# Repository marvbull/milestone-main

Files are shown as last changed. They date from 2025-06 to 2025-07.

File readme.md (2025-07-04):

# 🛠️ Assembly Station and Promotional gift

## 📖 Project Overview

This project involves the development of a **custom assembly station** for the **Baden-Wuerttemberg Cooperative State University (DHBW)**.  
It includes both the **design of a promotional giveaway** and the creation of a dedicated **robot-based assembly system** to mount it efficiently.

The system integrates a self-developed robotic arm and combines mechanical, electronic, and software components to form a complete, automated solution.

## 🎬 Demonstration Videos

Below are videos demonstrating the functionality of the assembly station:

- ▶️ [First Attempt – Basic Functionality Test](https://www.youtube.com/watch?v=XfHKRl_iYHc)  
- ✅ [Final Presentation – Fully Working Setup](https://www.youtube.com/watch?v=XNof5O9abk8)

## 📂 Repository Structure

- `src/` – Core source code (C++, Python, Arduino)
- `hardware/` – Circuit schematics (Altium)
- `cad/` – Mechanical models and assemblies (Fusion360, Creo)
- `docs/` – Technical documentation and risk assessment
- `README.md` – Project overview

## ⚙️ Technologies Used

- **C++ / Python / Arduino** – Embedded and control programming  
- **MATLAB** – Simulation and kinematic modeling  
- **Raspberry Pi** – System coordination and I²C communication  
- **Altium Designer** – PCB and electronics design  
- **Siemens NX / Creo** – Mechanical design and CAD modeling  
- **I²C** – Device communication between modules

## 🚀 Project Status

✅ **Completed**  
All planned development milestones have been achieved. The system is fully implemented, tested, and documented.

## 📄 License

This project is licensed under the **MIT License** – see the [LICENSE](./LICENSE) file for details.

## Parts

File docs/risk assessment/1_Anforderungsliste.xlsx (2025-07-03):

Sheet: Montageeinrichtung
Lfd. Nr | Hauptmerkmal | Anforderung / Spezifikation (Zahlen, Daten, Fakten) | Klassifizierung
A1 | Geometrie | Max. 600 x 400 x 400 mm [L x B x H] | LA | BA = Basisanforderung
A2 | Gewicht | Gewicht: Max. 12 kg | LA | LA = Leistungsanforderung
A3 | Kosten | Budget: Max. 750 € | LA | BE = Begeisterungsanforderung
A4 | Ergonomie | Lautstärke < 85 db (Nach Arbeitsschutzverordnung) | BE
A5 | Sicherheit | Erfüllung CE-Richtlinien | BA
A6 | Sicherheit | Die Maschinenrichtlinie muss eingehalten werden | BA
A7 | Sicherheit | Automatische Abschaltung der Anlage beim Öffnen des Gehäuses | BA
A8 | Sicherheit | Not-Aus muss vorhanden sein | BA
A9 | Sicherheit | Eingreifen während des Prozesses ist nicht möglich | LA
A10 | Sicherheit | Kein Zugang zum Montageprozess über das Ausgabefach | BA |  | wenn wir das reinschreiben, müssen wir es am ende auch nachweisen
A11 | Sicherheit | Keine Verletzungsgefahr am Gehäuse | LA
A12 | Sicherheit | Gehäuse: Schutz nach IP41 | LA
A13 | Sicherheit | Sicherer Stand | LA
A14 | Sicherheit | Transportsicher, 90° Kippung | BE
A15 | Elektrik | EMV-Richtlinie | BA
A16 | Elektrik | Elektrische Komponenten schutz | LA
A17 | Zeit | 10 Produkte in <5 min | LA
A18 | Lagerkapazität | Alle Lager müssen mindestens 10 Teile aufnehmen können | LA
A19 | Antrieb | Niederspannung (< 50 V) | LA
A20 | Energie | Elektrische Energie | BE
A21 | Produktivität | Montageablauf: vollautomatisch min. 3 Bauteile fügen | BA
A22 | Betrieb | Automatische Ausgabe des Produktes | BA
A23 | Bedienung | Interaktives Element | BE
A24 | Bedienung | Einzelkomponenten Füllstand (rot, grün) | BE
A25 | Werkstoff | Korrosionsbeständig | BE
A26 | Instandhaltung | Definierter Wartungszyklus /-aufwand | LA
A27 | Lebensdauer | Mind. 10.000 Montagezyklen ohne Reparatur | LA
A28 | Transport | Transportgriffe | BE
A29 | Design | Werbung für DHBW | BE
A30 | Design | Beleuchtung | BE
A31 | Design | Quetschsicheres Design | LA
A32 | Design | Einheitliches Design in DHBW Farben | BE
A33 | Design | Modulares Baugruppendesign | BE
A34 | Design | Sichtbarer, innovativer Montageprozess | LA

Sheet: Werbegeschenk
Lfd. Nr | Hauptmerkmal | Anforderung / Spezifikation (Zahlen, Daten, Fakten) | von wem | wann | Klassifizierung
A1 | Teile | min. 3 Bauteile |  |  | BA
A2 | Werkstoff | Korrosionsbeständig |  |  | BE
A3 | Preis | Preis pro Einzelstück: Max. 10 € |  |  | LA
A4 | Design | Werbung für DHBW |  |  | BE
A5 | Design | Magnet: N48H NdFeB mit 7 µm bis 13 µm NiCuNi Beschichtung |  |  | BA | **Apple Vorgabe
A6 | Sicherheit | Kindersicherheit, keine scharfen Kanten |  |  | LA
A7
 | Kapazität | verstauen von mind. 3 Karten möglich
 | Erweiterbar | erweiterbar um Module/Zwischenschichten, wie Geldfach
 | Sicherheit | auch bei Schütteln fallen Karten nicht raus
 | Stabilität | beide Platten müssen einen Sturz aus 3m höhe und ein Biegemoment von 10 Nm aushalten

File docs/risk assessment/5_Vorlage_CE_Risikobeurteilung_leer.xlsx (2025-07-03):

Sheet: Grenzen der Maschine
Grenzen einer MusterMaschine / eines MusterProduktes
Bestimmungsgemäße Nutzung
Die automatisierte Montageeinrichtung ist ausschließlich für den Zusammenbau des DailyM8's konzipiert. Dabei dürfen die Magazine nur mit den definierten Einzelteilen manuell aufgefüllt werden. Für diese manuelle Handhabung und für wartungsgemäße Arbeiten an der Anlage darf die Schutzklappe geöffnet werden. Bevor der Montageprozess jedoch startet muss die Schutzvorrichtung wieder verschlossen werden. Nach dem Start des Prozesses ist dieser nicht mehr zu unterbrechen, außer es ist ein Not-Halt erforderlich. Das fertige Produkt kann anschließend aus dem Ausgabefach entnommen werden.
Betriebsarten:
Automatisierter Prozess zur Herstellung von 10 DailyM8's
Stoppbetrieb zur manuellen Beladung der Magazine
Nothalt
Einsatzbereich:
Die automatisierte Montageeinrichtung wird ausschließlich in klimatisierten Innenräumen auf stabilem und geradem Untergrund.
Personenkreise, die mit der Maschine / dem Produkt in Berührung kommen
Eingewiesene Personen der DHBW Heidenheim.
Lebensphasen* | Personenkreise
 | MA Fertigung Montage | MA Lager | MA der Logisitk | Händler + MA | Kunde | Wartungs-personal | Kundendienst-MA | Schrott- händler
Produktion | x | x
Montage | x | x
Transport | x | x | x | x
Inbetriebnahme |  |  |  | x | x |  | x
Betrieb |  |  |  |  | x
Instandhaltung / Wartung |  |  |  |  | x | x
Fehlerfall |  |  |  |  | x | x | x
Außerbetriebnahme |  |  |  |  | x |  | x | x
Demontage |  |  |  |  | x |  | x | x
MA = Mitarbeiter
* s. Tabellenblatt Lebensphasen
Räumliche Grenzen (Wandabstand)
Die automatisierte Montageeinrichtung muss mindestens mit einem Abstand von 0,5 m zu jeder Wandseite betrieben werden.
Zeitliche Grenzen
Ein Durchlauf von 10 Produkten erfolgt in unter 5 min Betrieb und muss anschließend manuell aufgefüllt werden.
Weitere Grenzen
Betriebstemperatur: 10 °C bis 30 °C (Optimalfall: Raumtemperatur von 20 °C)
Luftfeuchtigkeit: relative Luftfeuchtigkeit von max. 70 %
Untergrund: Stabil, gerade und sauber
Bedienung: Nur durch unterwiesenes Personal
Vernünftigerweise vorhersehbare Fehlanwendungen:
Definition (vernünftigerweise vorhersehbare Fehlanwendungen): Tätigkeiten die mit der Maschine / dem Produkt innerhalb der gesamten Lebensdauer durch den in der Lebensphase jeweils definierten Personenkreis (z.B. Nutzer, Bedien- oder Fachpersonal) fälschlicherweise, vorsätzlich oder fahrlässig außerhalb der Grenzen der Maschine / des Produktes durchgeführt werden.
Auf richtiges Einlegen der definierten Komponenten an den definierten Orten ist zu achten.
Der Einsatz nicht genehmigter Hilfsstoffe ist nicht gestattet.
Der Einsatz in explosionsgefährdeten Bereichen ist verboten.
Es ist auf die vorgegebenen Wartungsintervalle zu achten.
Jegliche Störungen müssen sofort gemeldet werden und die Maschine ist aus dem Betrieb zu nehmen.
Warn- und Hinweisschilder dürfen nicht entfernt, bedeckt oder geändert werden.
Veränderungen an der Anlage sind nur mit schriftlicher Genehmigung gestattet.
Eingreifen über den Auswerfbehälter ist nicht gestattet.

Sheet: Lebensphasen
Lebensphasen für die Risikobeurteilung zur CE-Konformität
Produktion / Montage
Transport
Inbetriebnahme (Zusammenbau, Installation)
Betrieb
Instandhaltung / Wartung
Fehlerfall
Außerbetriebnahme
Demontage

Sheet: Aufgaben+Tätigkeiten
Aufgaben in der Lebensphase
Lfd. Nr. | Aufgabe / Tätigkeit
1
1 | Mülltrennung
2 | Einzelteile montieren
3 | Funktionstest von Elektrokomponenten
4 | Elektrokomponenten fachgerecht installieren
5 | Elektrokomponenten verlöten
6 | Verpacken
7 | Einladen
8 | Ausladen
9 | Entpacken
10 | Gehäuse verschrauben
11 | Funktionstest der Anlage
12 | Ladungssicherung
13 | Anschließen an Stromnetz
14 | Einweisung
15 | Magazine bestücken
16 | Anschalten
17 | Schutzhaube schließen
18 | Montagezyklus starten
19 | Ersatzteile lagern
20 | Partikuläre Demontage
21 | Not-Halt kontrollieren
22 | Fehler suchen
23 | Endmontage
24 | Wartungsprotokoll ausfüllen
25 | Reinigung der Anlage
26 | Magazine entleeren
27 | Kabel überprüfen
28 | Ursache finden und beseitigen
29 | Abschließen vom Stromnetz
30 | Demontage
31 | Mülltrennung
32 | Schrottabholung
33 | Montage

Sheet: Risikobeurteilung
Risikobeurteilung |  |  | Mustermaschine |  |  |  |  |  |  |  |  |  |  | Erstellt von: Häberle Annika
nach DIN EN ISO 12100:2011 |  |  |  |  |  |  |  |  |  |  |  |  |  | Gruppe 4 | Datum: 28.04.2025
Risikoanalyse |  |  |  |  |  | Risikobewertung
 |  |  |  |  |  |  |  |  |  |  |  |  |  |  |  |  |  |  |  |  | X
Lfd. Nr. | Lebensphase | Aufgabe/ Tätigkeit | Ursprung der Gefährdung durch Maschine, Umwelt und Mensch | Gefährdungsereignis | Folge der Gefährdung für Mensch | Häufigkeit (F) | Wahrscheinlichkeit (W) | Vermeidung (P) | Schwere (S) | Ergebnis (SIL) | konstruktive Maßnahme/ Verbesserung | Schutzmaßnahmen (technisch: ZUSÄTZLICHE Hard- und Software, Mechanik) | Montageanweisung | Handbuch (Betriebsanleitung) | Häufigkeit (F) | Wahrscheinlichkeit (W) | Vermeidung (P) | Schwere (S) | Ergebnis (SIL) | Warnung vor Restrisiken |  | Lebensphase | Anwendung/Funktion | Aufgabe/ Tätigkeit | Ursprung der Gefährdung durch Maschine, Umwelt und Mensch | Gefährdungsereignis | Folge der Gefährdung für Mensch
1 | Produktion / Montage | Transport der Einzelteile | U1.6 herabfallende Gegenstände | Herabfallen oder Ausstoß von Objekten | F1.3 Quetschen | 3 | 3 | 3 | 2 | AM |  |  |  |  |  |  |  |  |  |  |  | Produktion / Montage (beim Hersteller, innerbetrieblich) | Test | #REF! | Ursprung | Ausfall von Einrichtungen zum Anhalten von sich bewegenden Teilen | F1 Mechanische Gefährdung
2 |  |  | U1.14 scharfe Kanten | Kontakt mit scharfen Kanten und Ecken, vorstehenden Teilen | F1.4 Schneiden oder Abschneiden | 3 | 4 | 2 | 2 | AM |  |  |  |  |  |  |  |  |  |  |  | Transport (innerbetrieblich) | #REF! | #REF! | U1 Mechanische Gefährdung | Bruch während des Betriebs | F1.1 überfahren werden
3 |  |  | U1.7 Schwerkraft (gespeicherte Energie) | schmerzhafte und ermüdende Körperhaltungen | F5.5 Wirbelsäulenverletzung | 2 | 3 | 1 | 3 | AM |  |  |  |  |  |  |  |  |  |  |  | Transport (zum Kunden) | #REF! | #REF! | U1.1 Beschleunigung/Abbremsung (kinetische Energie) | direkter Kontakt | F1.2 weggeschleudert werden
4 |  | Einzelteile montieren | U1.6 herabfallende Gegenstände | Herabfallen oder Ausstoß von Objekten | F1.3 Quetschen | 3 | 4 | 3 | 3 | SIL1 |  |  |  |  |  |  |  |  |  |  |  | Transport (beim Kunden innerbetrieblich) | #REF! | #REF! | U1.2 spitze Teile | Durchschlag | F1.3 Quetschen
5 |  |  | U1.7 Schwerkraft (gespeicherte Energie) | schmerzhafte und ermüdende Körperhaltungen | F5.5 Wirbelsäulenverletzung | 2 | 2 | 1 | 3 | AM |  |  |  |  |  |  |  |  |  |  |  | Inbetriebnahme (Zusammenbau, Installation) | #REF! | #REF! | U1.3 Annäherung eines sich bewegenden Teiles | Emission eines Geräuschpegels, der gefährdend sein kann | F1.4 Schneiden oder Abschneiden
6 |  |  | U1.3 Annäherung eines sich bewegenden Teiles | Verschieben sich bewegender Teile | F1.3 Quetschen | 2 | 2 | 3 | 4 | SIL2 |  | Handschuhe tragen | Montage zu 2. |  | 2 | 1 | 2 | 3 | AM |  |  | Einrichten | #REF! | #REF! | U1.4 schneidende Teile | Emission eines Geräuschpegels, der zu Störungen der Sprachkommunikation oder zu Störungen akustischer Signale führen kann | F1.5 Einziehen oder Fangen
7 |  |  | U1.14 scharfe Kanten | direkter Kontakt | F1.4 Schneiden oder Abschneiden | 3 | 4 | 3 | 3 | SIL1 |  |  |  |  |  |  |  |  |  |  |  | Betrieb | #REF! | #REF! | U1.5 elastische Elemente | Emission eines Schwingungspegels, der gefährdend sein kann | F1.6 Erfassen
8 |  |  |  | Kontakt mit scharfen Kanten und Ecken, vorstehenden Teilen | F1.4 Schneiden oder Abschneiden | 3 | 3 | 4 | 3 | SIL1 |  |  |  |  |  |  |  |  |  |  |  | Reinigung | #REF! | #REF! | U1.6 herabfallende Gegenstände | Emission eines Stoffes, der gefährdend sein kann | F1.7 Reiben oder Abschürfen
9 |  | Funktionstest von Elektrokomponenten | U2.4 spannungsführende Teile | direkter Kontakt | F2.8 (elektrischer) Schlag | 2 | 3 | 3 | 3 | SIL1 |  |  |  |  |  |  |  |  |  |  |  | Instandhaltung / Wartung | #REF! | #REF! | U1.7 Schwerkraft (gespeicherte Energie) | Emission von Strahlungsfeldern, die gefährdend sein können | F1.8 Stoß
10 |  |  | U2.6 Überlast | Kurzschluss | F2 Elektrische Gefährdungen | 1 | 1 | 3 | 2 | - |  |  |  |  |  |  |  |  |  |  |  | Fehlerfall | #REF! | #REF! | U1.8 Höhe gegenüber dem Boden | Feuer | F1.9 Eindringen von unter Druck stehenden Medien
11 |  |  | U2.8 Kurzschluss | Kurzschluss | F2.8 (elektrischer) Schlag | 1 | 2 | 3 | 2 | - |  |  |  |  |  |  |  |  |  |  |  | Außerbetriebnahme / Demontage | #REF! | #REF! | U1.9 Hochdruck | Herabfallen oder Ausstoß von Objekten | F1.10 Scheren
12 |  | Elektrokomponenten verlöten | U3.3 Objekte oder Materialien hoher oder niedriger Temperatur | direkter Kontakt | F3.1 Verbrennung | 2 | 3 | 2 | 3 | AM |  |  |  |  |  |  |  |  |  |  |  |  |  | #REF! | U1.10 Beweglichkeit der Maschine | Herabfallen oder Herausschleudern eines sich bewegenden Maschinenteils oder eines in der Maschine festgeklemmten Werkstückes | F1.11 Ausrutschen, Stolpern oder Stürzen
13 |  | Elektrokomponenten fachgerecht installieren | U2.4 spannungsführende Teile | direkter Kontakt | F2.3 Auswirkungen auf medizinische Implantate | 1 | 3 | 4 | 3 | SIL1 |  |  |  |  |  |  |  |  |  |  |  |  |  | #REF! | U1.11 sich bewegende Teile | Herausspritzen von Flüssigkeiten unter hohem Druck | F1.12 Durchstich oder Einstich
14 |  |  | U1.14 scharfe Kanten | direkter Kontakt | F1.4 Schneiden oder Abschneiden | 2 | 3 | 3 | 2 | AM |  |  |  |  |  |  |  |  |  |  |  |  |  | #REF! | U1.12 rotierende Teile | indirekter Kontakt | F1.13 Ersticken
15 |  |  |  | Kontakt mit scharfen Kanten und Ecken, vorstehenden Teilen | F1.4 Schneiden oder Abschneiden | 3 | 3 | 2 | 2 | AM |  |  |  |  |  |  |  |  |  |  |  |  |  | #REF! | U1.13 raue, rutschige Oberfläche | Kontakt mit Objekten hoher oder geringer Temperatur | ./.
16 |  |  | U1.2 spitze Teile | Kontakt mit scharfen Kanten und Ecken, vorstehenden Teilen | F1.12 Durchstich oder Einstich | 3 | 4 | 3 | 1 | - |  |  |  |  |  |  |  |  |  |  |  |  |  | #REF! | U1.14 scharfe Kanten | Kontakt mit rauen Oberflächen | ./.
17 |  |  | U8.3 Gestaltung, Anordnung oder Erkennung | weitere Gefährdungsereignisse durch Ausfälle oder unzureichende Konstruktion der Steuerung | F8.5 alle weiteren (z.B. mechanischen, elektrischen) Probleme als Folge menschlichen Fehlverhaltens | 3 | 4 | 1 | 1 | - |  |  |  |  |  |  |  |  |  |  |  |  |  | #REF! | U1.15 Standfestigkeit/-sicherheit | Kontakt mit rotierenden offenen Enden | ./.
18 |  | Gehäuse verschrauben | U1.6 herabfallende Gegenstände | Herabfallen oder Herausschleudern eines sich bewegenden Maschinenteils oder eines in der Maschine festgeklemmten Werkstückes | F1.3 Quetschen | 2 | 3 | 4 | 3 | SIL1 |  |  |  |  |  |  |  |  |  |  |  |  |  | #REF! | U1.16 Vakuum | Kontakt mit scharfen Kanten und Ecken, vorstehenden Teilen | 0
19 |  | Funktionstest der Anlage | U1.11 sich bewegende Teile | direkter Kontakt | F1.3 Quetschen | 2 | 2 | 1 | 3 | AM |  |  |  |  |  |  |  |  |  |  |  |  |  | #REF! | U1.17 Beschleunigung/Abbremsung | Kurzschluss | 0
20 |  |  | U1.12 rotierende Teile | direkter Kontakt | F1.4 Schneiden oder Abschneiden | 2 | 1 | 3 | 2 | - |  |  |  |  |  |  |  |  |  |  |  |  |  | #REF! | U1.18 Annäherung eines sich bewegenden Teils an ein feststehendes Teil | Lichtbogen | F2 Elektrische Gefährdungen
21 |  |  | U2.4 spannungsführende Teile | direkter Kontakt | F2.3 Auswirkungen auf medizinische Implantate | 3 | 3 | 4 | 3 | SIL1 |  |  |  |  |  |  |  |  |  |  |  |  |  | #REF! | U2 Elektrische Gefährdungen | Maschinentätigkeit als Ergebnis der Wirkungslosigkeit (Umgehen oder Ausfall) von Schutzeinrichtungen | F2.1 Verbrennung
22 |  | Verpacken | U1.14 scharfe Kanten | Kontakt mit scharfen Kanten und Ecken, vorstehenden Teilen | F1.4 Schneiden oder Abschneiden | 2 | 3 | 3 | 1 | - |  |  |  |  |  |  |  |  |  |  |  |  |  | #REF! | U2.1 Lichtbogen | menschliche Fehler/ menschliches Fehlverhalten (unbeabsichtigt und/oder vorsätzlich durch die Konstruktion hervorgerufen) | F2.2 chemische Reaktionen
23 |  |  | U10.1 z.B. sich wiederholende Tätigkeit + Anstrengung + hohe Umgebungstemperatur | übermäßige Anstrengung | F5.5 Wirbelsäulenverletzung | 4 | 2 | 2 | 3 | SIL1 |  |  |  |  |  |  |  |  |  |  |  |  |  | #REF! | U2.2 elektromagnetische Vorgänge | raue Umgebungsbedingungen | F2.3 Auswirkungen auf medizinische Implantate
24 |  | Einladen | U1.7 Schwerkraft (gespeicherte Energie) | schmerzhafte und ermüdende Körperhaltungen | F5.5 Wirbelsäulenverletzung | 4 | 3 | 2 | 3 | SIL1 |  |  |  |  |  |  |  |  |  |  |  |  |  | #REF! | U2.3 elektrostatische Vorgänge | schmerzhafte und ermüdende Körperhaltungen | F2.4 tödlilcher Stromschlag
25 |  |  | U1.6 herabfallende Gegenstände | Herabfallen oder Ausstoß von Objekten | F1.3 Quetschen | 2 | 2 | 2 | 4 | SIL2 |  | Sicherheitsschuhe tragen, Helm tragen |  |  | 1 | 1 | 1 | 4 | SIL2 | Objekte können trotz Sicherung herabfallen |  |  |  | #REF! | U2.4 spannungsführende Teile | sich in hoher Frequenz wiederholende Tätigkeiten | F2.5 Stürzen, weggeschleudert werden
26 |  | Ladungssicherung | U1.6 herabfallende Gegenstände | Herabfallen oder Ausstoß von Objekten | F1.3 Quetschen | 2 | 2 | 1 | 4 | SIL2 |  | Sicherheitsschuhe tragen, Helm tragen |  |  | 1 | 2 | 1 | 3 | - |  |  |  |  | #REF! | U2.5 unzureichender Abstand zu unter Hochspannung stehenden Teilen | übermäßige Anstrengung | F2.6 Feuer
27 |  |  | U1.17 Beschleunigung/Abbremsung | ungesteuerte Bewegungen (einschließlich Geschwindigkeitsänderung) | F1.3 Quetschen | 1 | 2 | 1 | 3 | - |  |  |  |  |  |  |  |  |  |  |  |  |  | #REF! | U2.6 Überlast | unbeabsichtigter/unerwarteter Anlauf | F2.7 Herausschleudern von geschmolzenen Teilen
28 |  | Ausladen | U1.6 herabfallende Gegenstände | Herabfallen oder Ausstoß von Objekten | F1.3 Quetschen | 1 | 2 | 3 | 2 | - |  |  |  |  |  |  |  |  |  |  |  |  |  | #REF! | U2.7 Teile, die im Fehlerzustand spannungsführend geworden sind | ungesteuerte Bewegungen | F2.8 (elektrischer) Schlag
29 |  |  | U1.7 Schwerkraft (gespeicherte Energie) | schmerzhafte und ermüdende Körperhaltungen | F5.5 Wirbelsäulenverletzung | 1 | 2 | 1 | 3 | - |  |  |  |  |  |  |  |  |  |  |  |  |  | #REF! | U2.8 Kurzschluss | ungesteuerte Bewegungen (einschließlich Geschwindigkeitsänderung) | ./.
30 |  |  | U1.8 Höhe gegenüber dem Boden | Herabfallen oder Ausstoß von Objekten | F1.3 Quetschen | 3 | 4 | 4 | 2 | SIL1 |  |  |  |  |  |  |  |  |  |  |  |  |  | #REF! | U2.9 Wärmestrahlung | Verlust der direkten Sichtbarkeit des Arbeitsbereiches | F3 Thermische Gefährdungen
31 |  | Entpacken | U1.2 spitze Teile | direkter Kontakt | F1.3 Quetschen | 2 | 3 | 2 | 2 | - |  |  |  |  |  |  |  |  |  |  |  |  |  | #REF! | U3 Thermische Gefährdungen | Verlust der Standfestigkeit/-sicherheit | F3.1 Verbrennung
32 |  |  |  |  | F1.4 Schneiden oder Abschneiden | 2 | 3 | 3 | 2 | AM |  |  |  |  |  |  |  |  |  |  |  |  |  | #REF! | U3.1 Explosiion | Verschieben sich bewegender Teile | F3.2 Dehydrierung
33 |  |  | U1.14 scharfe Kanten | direkter Kontakt | F1.4 Schneiden oder Abschneiden | 2 | 4 | 2 | 2 | AM |  |  |  |  |  |  |  |  |  |  |  |  |  | #REF! | U3.2 Flamme | weitere Gefährdungsereignisse durch Ausfälle oder unzureichende Konstruktion der Steuerung | F3.3 Unbehagen
34 |  |  |  | Kontakt mit scharfen Kanten und Ecken, vorstehenden Teilen | F1.4 Schneiden oder Abschneiden | 3 | 4 | 3 | 2 | AM |  |  |  |  |  |  |  |  |  |  |  |  |  | #REF! | U3.3 Objekte oder Materialien hoher oder niedriger Temperatur | Zugang zu/Kontakt mit beweglichen Teilen | F3.4 Erfrierung
35 |  |  | U1.13 raue, rutschige Oberfläche | Kontakt mit rauen Oberflächen | F1.7 Reiben oder Abschürfen | 2 | 3 | 3 | 1 | - |  |  |  |  |  |  |  |  |  |  |  |  |  | #REF! | U3.4 Strahlung von Wärmequellen |  | F3.5 Verletzungen durch Strahlung von Wärmequellen
36 |  |  | U1.10 Beweglichkeit der Maschine | Kontakt mit scharfen Kanten und Ecken, vorstehenden Teilen | F1.4 Schneiden oder Abschneiden | 1 | 2 | 3 | 1 | - |  |  |  |  |  |  |  |  |  |  |  |  |  | #REF! | ./. |  | F3.6 Verbrühung
37 |  | Elektrokomponenten fachgerecht installieren | U2.4 spannungsführende Teile | direkter Kontakt | F2.8 (elektrischer) Schlag | 1 | 4 | 3 | 4 | SIL2 | FI-Schutzschalter verwenden |  |  |  | 1 | 2 | 2 | 3 | AM |  |  |  |  | #REF! | ./. |  | F4 Gefährdung durch Lärm
38 |  |  |  |  | F2.3 Auswirkungen auf medizinische Implantate | 1 | 3 | 4 | 3 | SIL1 |  |  |  |  |  |  |  |  |  |  |  |  |  | #REF! | U4 Gefährdung durch Lärm |  | F4.1 Unbehagen
39 |  | Einweisung | U9 Gefährdungen im Zusammenhang mit der Einsatzumgebung der Maschine | menschliche Fehler/ menschliches Fehlverhalten (unbeabsichtigt und/oder vorsätzlich durch die Konstruktion hervorgerufen) | F1.11 Ausrutschen, Stolpern oder Stürzen | 2 | 3 | 5 | 2 | AM |  |  |  |  |  |  |  |  |  |  |  |  |  | #REF! | U4.1 Kavitationsvorgänge |  | F4.2 Bewusstseinsverlust
40 |  | Magazine bestücken | U1.2 spitze Teile | direkter Kontakt | F1.3 Quetschen | 2 | 3 | 3 | 2 | AM |  |  |  |  |  |  |  |  |  |  |  |  |  | #REF! | U4.2 Abluftsystem |  | F4.3 Gleichgewichtsstörung
41 |  |  |  |  | F1.4 Schneiden oder Abschneiden | 2 | 4 | 2 | 2 | AM |  |  |  |  |  |  |  |  |  |  |  |  |  | #REF! | U4.3 mit hoher Geschwindigkeit austretendes Gas |  | F4.4 bleibender Gehörverlust
42 |  |  | U1.14 scharfe Kanten | direkter Kontakt | F1.4 Schneiden oder Abschneiden | 3 | 4 | 3 | 2 | AM |  |  |  |  |  |  |  |  |  |  |  |  |  | #REF! | U4.4 Herstellungsprozess (Stanzen, Schneiden usw.) |  | F4.5 Stress
43 |  |  |  | Kontakt mit scharfen Kanten und Ecken, vorstehenden Teilen | F1.4 Schneiden oder Abschneiden | 2 | 3 | 2 | 2 | - |  |  |  |  |  |  |  |  |  |  |  |  |  | #REF! | U4.5 bewegliche Teile |  | F4.6 Tinnitus (Ohrensausen)
44 |  | Anschalten | U4.8 pfeifende Pneumatik-Einrichtungen | Emission eines Geräuschpegels, der zu Störungen der Sprachkommunikation oder zu Störungen akustischer Signale führen kann | F4.1 Unbehagen | 3 | 3 | 4 | 1 | - |  |  |  |  |  |  |  |  |  |  |  |  |  | #REF! | U4.6 reibende Flächen |  | F4.7 Ermüdung
45 |  |  |  |  | F4.5 Stress | 2 | 3 | 3 | 2 | AM |  |  |  |  |  |  |  |  |  |  |  |  |  | #REF! | U4.7 mit Unwucht rotierende Teile |  | F4.8 alle weiteren (z.B. mechanischen, elektrischen) Probleme als Folge einer Störung der Sprachkommunikation oder einer Störung akustischer Signale
46 |  |  |  |  | F6.5 Kopfschmerzen, Schlaflosigkeit usw. | 4 | 3 | 4 | 1 | AM |  |  |  |  |  |  |  |  |  |  |  |  |  | #REF! | U4.8 pfeifende Pneumatik-Einrichtungen |  | ./.
47 |  |  | U2.4 spannungsführende Teile | direkter Kontakt | F2.3 Auswirkungen auf medizinische Implantate | 1 | 3 | 4 | 3 | SIL1 |  |  |  |  |  |  |  |  |  |  |  |  |  | #REF! | U4.9 verschlissene Teile |  | F5 Gefährdung durch Schwingungen
48 |  |  |  |  | F2.8 (elektrischer) Schlag | 1 | 4 | 3 | 3 | SIL1 |  |  |  |  |  |  |  |  |  |  |  |  |  | #REF! | U5 Gefährdung durch Schwingungen |  | F5.1 Unbehagen
49 |  | Schutzhaube schließen | U1.18 Annäherung eines sich bewegenden Teils an ein feststehendes Teil | direkter Kontakt | F1.3 Quetschen | 1 | 3 | 3 | 3 | AM |  |  |  |  |  |  |  |  |  |  |  |  |  | #REF! | U5.1 Kavitationsvorgänge |  | F5.2 Erkrankungen der unteren Wirbelsäule
50 |  | Montagezyklus starten | U4.8 pfeifende Pneumatik-Einrichtungen | Emission eines Geräuschpegels, der zu Störungen der Sprachkommunikation oder zu Störungen akustischer Signale führen kann | F4.5 Stress | 2 | 3 | 3 | 2 | AM |  |  |  |  |  |  |  |  |  |  |  |  |  | #REF! | U5.2 Fehlausrichtung sich bewegender Teile |  | F5.3 neurologische Erkrankung
51 |  |  |  |  | F4.1 Unbehagen | 3 | 3 | 4 | 1 | - |  |  |  |  |  |  |  |  |  |  |  |  |  | #REF! | U5.3 bewegliche Ausrüstung |  | F5.4 Knochengelenkschaden
52 |  |  |  |  | F6.5 Kopfschmerzen, Schlaflosigkeit usw. | 4 | 3 | 4 | 1 | AM |  |  |  |  |  |  |  |  |  |  |  |  |  | #REF! | U5.4 reibende Flächen |  | F5.5 Wirbelsäulenverletzung
53 |  | Ersatzteile lagern | U1.7 Schwerkraft (gespeicherte Energie) | übermäßige Anstrengung | F5.2 Erkrankungen der unteren Wirbelsäule | 1 | 3 | 2 | 4 | SIL2 |  | Hebehilfen verwenden |  | Wiederholtes Heben kann zu gesundheitlichen Schäden führen | 1 | 2 | 1 | 3 | - |  |  |  |  | #REF! | U5.5 mit Unwucht rotierende Teile |  | F5.6 Gefäßerkrankungen
54 |  |  | U1.6 herabfallende Gegenstände | Herabfallen oder Ausstoß von Objekten | F1.2 weggeschleudert werden | 3 | 3 | 2 | 2 | AM |  |  |  |  |  |  |  |  |  |  |  |  |  | #REF! | U5.6 schwingende Ausrüstung |  | ./.
55 |  | Partikuläre Demontage | U1.6 herabfallende Gegenstände | Herabfallen oder Ausstoß von Objekten | F1.3 Quetschen | 2 | 3 | 2 | 3 | AM |  |  |  |  |  |  |  |  |  |  |  |  |  | #REF! | U5.7 verschlissene Teile |  | F6 Gefährdung durch Strahlung
56 |  |  | U1.7 Schwerkraft (gespeicherte Energie) | schmerzhafte und ermüdende Körperhaltungen | F5.5 Wirbelsäulenverletzung | 2 | 1 | 3 | 4 | SIL2 |  | Hebehilfen verwenden |  | Wiederholtes Heben kann zu gesundheitlichen Schäden führen | 1 | 2 | 1 | 3 | - |  |  |  |  | #REF! | U6 Gefährdung durch Strahlung |  | F6.1 Verbrennung
57 |  |  | U1.14 scharfe Kanten | Kontakt mit scharfen Kanten und Ecken, vorstehenden Teilen | F1.4 Schneiden oder Abschneiden | 3 | 2 | 2 | 2 | - |  |  |  |  |  |  |  |  |  |  |  |  |  | #REF! | U6.1 ionisierende Strahlungsquelle |  | F6.2 Augen- und Hautschädigung
58 |  | Montagezyklus starten | U1.3 Annäherung eines sich bewegenden Teiles | Verschieben sich bewegender Teile | F1.3 Quetschen | 2 | 3 | 2 | 3 | AM |  |  |  |  |  |  |  |  |  |  |  |  |  | #REF! | U6.2 niederfrequente elektromagnetische Strahlung |  | F6.3 Auswirkungen auf die Fortpflanzungsfähigkeit
59 |  |  | U1.7 Schwerkraft (gespeicherte Energie) | schmerzhafte und ermüdende Körperhaltungen | F5.5 Wirbelsäulenverletzung | 2 | 1 | 3 | 3 | AM |  |  |  |  |  |  |  |  |  |  |  |  |  | #REF! | U6.3 optische Strahlung (infrarot, sichtbar und ultraviolett) einschließlich Laserstrahlen |  | F6.4 genetische Veränderung
60 |  |  | U1.6 herabfallende Gegenstände | Herabfallen oder Ausstoß von Objekten | F1.3 Quetschen | 2 | 3 | 2 | 3 | AM |  |  |  |  |  |  |  |  |  |  |  |  |  | #REF! | U6.4 hochfrequente elektromagnetische Strahlung |  | F6.5 Kopfschmerzen, Schlaflosigkeit usw.
61 |  |  | U1.14 scharfe Kanten | direkter Kontakt | F1.4 Schneiden oder Abschneiden | 2 | 3 | 3 | 3 | SIL1 |  |  |  |  |  |  |  |  |  |  |  |  |  | #REF! | ./. |  | F7 Gefährdungen durch Materialien und Stoffe
62 |  |  |  | Kontakt mit scharfen Kanten und Ecken, vorstehenden Teilen | F1.4 Schneiden oder Abschneiden | 1 | 2 | 2 | 3 | AM |  |  |  |  |  |  |  |  |  |  |  |  |  | #REF! | U7 Gefährdungen durch Materialien und Stoffe |  | F7.1 Atembeschwerden, Ersticken
63 |  | Not-Halt kontrollieren | U1.10 Beweglichkeit der Maschine | Ausfall von Einrichtungen zum Anhalten von sich bewegenden Teilen | F9.5 alle weiteren Probleme, die als Folge der Auswirkungen der Gefährdungsquellen an der Maschine oder an Teilen der Maschine auftreten | 1 | 1 | 5 | 3 | AM |  |  |  |  |  |  |  |  |  |  |  |  |  | #REF! | U7.1 Aerosole |  | F7.2 Krebs
64 |  | Wartungsprotokoll ausfüllen | U8.7 psychische Überbelastung/Unterforderung | menschliche Fehler/ menschliches Fehlverhalten (unbeabsichtigt und/oder vorsätzlich durch die Konstruktion hervorgerufen) | F10 Kombination von Gefährdungen | 3 | 3 | 3 | 2 | AM |  |  |  |  |  |  |  |  |  |  |  |  |  | #REF! | U7.2 biologische und mikrobiologische (Viren, Bakterien, Pilze) |  | F7.3 Korrosion
65 |  | Not-Halt betätigen | U1.10 Beweglichkeit der Maschine | Ausfall von Einrichtungen zum Anhalten von sich bewegenden Teilen | F9.5 alle weiteren Probleme, die als Folge der Auswirkungen der Gefährdungsquellen an der Maschine oder an Teilen der Maschine auftreten | 1 | 1 | 5 | 3 | AM |  |  |  |  |  |  |  |  |  |  |  |  |  | #REF! | U7.3 Brennstoffe |  | F7.4 Auswirkungen auf die Fortpflanzungsfähigkeit
66 |  | Fehler suchen | U4.8 pfeifende Pneumatik-Einrichtungen | Emission eines Geräuschpegels, der zu Störungen der Sprachkommunikation oder zu Störungen akustischer Signale führen kann | F4.1 Unbehagen | 3 | 3 | 4 | 1 | - |  |  |  |  |  |  |  |  |  |  |  |  |  | #REF! | U7.4 Stäube |  | F7.5 Explosion
67 |  |  |  |  | F4.5 Stress | 2 | 3 | 3 | 2 | AM |  |  |  |  |  |  |  |  |  |  |  |  |  | #REF! | U7.5 Explosivstoffe |  | F7.6 Feuer
68 |  |  |  |  | F6.5 Kopfschmerzen, Schlaflosigkeit usw. | 4 | 3 | 4 | 1 | AM |  |  |  |  |  |  |  |  |  |  |  |  |  | #REF! | U7.6 Fasern |  | F7.7 Infektion
69 |  |  | U1.2 spitze Teile | direkter Kontakt | F1.3 Quetschen | 2 | 2 | 3 | 2 | - |  |  |  |  |  |  |  |  |  |  |  |  |  | #REF! | U7.7 feuergefährliches Material |  | F7.8 Veränderungen des Erbguts
70 |  |  |  |  | F1.4 Schneiden oder Abschneiden | 3 | 2 | 2 | 3 | AM |  |  |  |  |  |  |  |  |  |  |  |  |  | #REF! | U7.8 Flüssigkeiten |  | F7.9 Vergiftung
71 |  |  | U1.14 scharfe Kanten | direkter Kontakt | F1.4 Schneiden oder Abschneiden | 2 | 2 | 3 | 2 | - |  |  |  |  |  |  |  |  |  |  |  |  |  | #REF! | U7.9 Dämpfe |  | F7.10 Sensibilisierung
72 |  |  |  | Kontakt mit scharfen Kanten und Ecken, vorstehenden Teilen | F1.4 Schneiden oder Abschneiden | 3 | 3 | 2 | 3 | SIL1 |  |  |  |  |  |  |  |  |  |  |  |  |  | #REF! | U7.10 Gase |  | ./.
73 |  |  | U2.7 Teile, die im Fehlerzustand spannungsführend geworden sind | direkter Kontakt | F2.3 Auswirkungen auf medizinische Implantate | 2 | 3 | 4 | 3 | SIL1 |  |  |  |  |  |  |  |  |  |  |  |  |  | #REF! | U7.11 Nebel |  | ./.
74 |  |  |  |  | F2.8 (elektrischer) Schlag | 3 | 4 | 3 | 3 | SIL1 |  |  |  |  |  |  |  |  |  |  |  |  |  | #REF! | U7.12 Oxidationsmittel |  | F8 Gefährdung durch unergonomische Gestaltung
75 |  |  | U2.8 Kurzschluss | Kurzschluss | F2.8 (elektrischer) Schlag | 2 | 3 | 4 | 2 | AM |  |  |  |  |  |  |  |  |  |  |  |  |  | #REF! | U8 Gefährdung durch unergonomische Gestaltung |  | F8.1 Unbehagen
76 |  |  | U5.7 verschlissene Teile | direkter Kontakt | F1.4 Schneiden oder Abschneiden | 2 | 3 | 3 | 3 | SIL1 |  |  |  |  |  |  |  |  |  |  |  |  |  | #REF! | U8.1 Zugang |  | F8.2 Ermüdung
77 |  |  |  |  | F1.7 Reiben oder Abschürfen | 3 | 2 | 2 | 2 | - |  |  |  |  |  |  |  |  |  |  |  |  |  | #REF! | U8.2 Gestaltung oder Anordnung von Anzeigen |  | F8.3 Störungen des Bewegungsapparates
78 |  | Ursache finden und beseitigen | U8.7 psychische Überbelastung/Unterforderung | menschliche Fehler/ menschliches Fehlverhalten (unbeabsichtigt und/oder vorsätzlich durch die Konstruktion hervorgerufen) | F8.4 Stress | 1 | 2 | 1 | 2 | - |  |  |  |  |  |  |  |  |  |  |  |  |  | #REF! | U8.3 Gestaltung, Anordnung oder Erkennung |  | F8.4 Stress
79 |  |  | U2.7 Teile, die im Fehlerzustand spannungsführend geworden sind | direkter Kontakt | F2.8 (elektrischer) Schlag | 2 | 2 | 3 | 2 | - |  |  |  |  |  |  |  |  |  |  |  |  |  | #REF! | U8.4 Anstrengung |  | F8.5 alle weiteren (z.B. mechanischen, elektrischen) Probleme als Folge menschlichen Fehlverhaltens
80 |  |  | U1.11 sich bewegende Teile | unbeabsichtigter/unerwarteter Anlauf | F1.4 Schneiden oder Abschneiden | 3 | 3 | 1 | 4 | SIL2 |  |  |  | Hinweis: Bei Fehlerfall Maschine vom Netz nehmen | 2 | 1 | 1 | 3 | - |  |  |  |  | #REF! | U8.5 Flackern, Blenden, Schattenbildung und stroboskopische Effekte |  | ./.
81 |  | Abschließen vom Stromnetz | U2.7 Teile, die im Fehlerzustand spannungsführend geworden sind | Kurzschluss | F2.8 (elektrischer) Schlag | 2 | 2 | 3 | 2 | - |  |  |  |  |  |  |  |  |  |  |  |  |  | #REF! | U8.6 örtliche Beleuchtung |  | ./.
82 |  |  |  |  | F2.4 tödlilcher Stromschlag | 1 | 2 | 2 | 5 | SIL3 | FI-Schutzschalter verwenden | Schutzhandschuhe anziehen, Feuchtigkeit vermeiden |  |  | 1 | 2 | 1 | 3 | - |  |  |  |  | #REF! | U8.7 psychische Überbelastung/Unterforderung |  | ./.
83 |  | Demontage | U1.6 herabfallende Gegenstände | Herabfallen oder Ausstoß von Objekten | F1.3 Quetschen | 2 | 3 | 2 | 2 | - |  |  |  |  |  |  |  |  |  |  |  |  |  | #REF! | U8.8 Körperhaltung |  | ./.
84 |  |  | U1.14 scharfe Kanten | Kontakt mit scharfen Kanten und Ecken, vorstehenden Teilen | F1.4 Schneiden oder Abschneiden | 3 | 3 | 2 | 3 | SIL1 |  |  |  |  |  |  |  |  |  |  |  |  |  | #REF! | U8.9 sich wiederholende Tätigkeiten |  | ./.
85 |  |  | U1.7 Schwerkraft (gespeicherte Energie) | schmerzhafte und ermüdende Körperhaltungen | F5.5 Wirbelsäulenverletzung | 2 | 2 | 3 | 3 | AM |  |  |  |  |  |  |  |  |  |  |  |  |  | #REF! | U8.10 Sichtbarkeit |  | F9 Gefährdungen im Zusammenhang mit der Einsatzumgebung der Maschine
86 |  | Mülltrennung | U1.2 spitze Teile | Kontakt mit scharfen Kanten und Ecken, vorstehenden Teilen | F1.12 Durchstich oder Einstich | 2 | 3 | 3 | 3 | SIL1 |  |  |  |  |  |  |  |  |  |  |  |  |  | #REF! | U9 Gefährdungen im Zusammenhang mit der Einsatzumgebung der Maschine |  | F9.1 Verbrennungen
87 |  |  | U1.6 herabfallende Gegenstände | Herabfallen oder Ausstoß von Objekten | F1.3 Quetschen | 1 | 2 | 3 | 3 | AM |  |  |  |  |  |  |  |  |  |  |  |  |  | #REF! | U9.1 Staub und Nebel |  | F9.2 leichte Erkrankungen
88 |  |  | U1.14 scharfe Kanten | Kontakt mit scharfen Kanten und Ecken, vorstehenden Teilen | F1.4 Schneiden oder Abschneiden | 3 | 3 | 1 | 4 | SIL2 |  | Schutzhandschuhe tragen bei der Entsorgung |  |  | 2 | 3 | 1 | 3 | AM |  |  |  |  | #REF! | U9.2 elektromagnetische Störungen |  | F9.3 Ausrutschen, Stürzen
89 |  |  |  |  |  |  |  |  |  |  |  |  |  |  |  |  |  |  |  |  |  |  |  | #REF! | U9.3 Blitzschlag |  | F9.4 Ersticken
90 |  |  |  |  |  |  |  |  |  |  |  |  |  |  |  |  |  |  |  |  |  |  |  | #REF! | U9.4 Feuchtigkeit |  | F9.5 alle weiteren Probleme, die als Folge der Auswirkungen der Gefährdungsquellen an der Maschine oder an Teilen der Maschine auftreten
91 |  |  |  |  |  |  |  |  |  |  |  |  |  |  |  |  |  |  |  |  |  |  |  | #REF! | U9.5 Verunreinigungen |  | ./.
92 |  |  |  |  |  |  |  |  |  |  |  |  |  |  |  |  |  |  |  |  |  |  |  | #REF! | U9.6 Schnee |  | ./.
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

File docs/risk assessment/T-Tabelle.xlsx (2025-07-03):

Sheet: T-Tabelle
 | Spezifikationen |  |  |  |  |  |  |  |  |  |  |  |  |  |  |  |  |  |  |  |  |  |  |  |  |  |  |  |  |  |  |  |  |  |  |  |  | Baugruppen
 | Geometrie | Gewicht | Kosten | Ergonomie | Sicherheit | Sicherheit | Sicherheit | Sicherheit | Sicherheit | Sicherheit | Sicherheit | Sicherheit | Sicherheit | Sicherheit | Elektrik | Elektrik | Zeit | Lagerkapazität | Antrieb | Energie | Produktivität | Betrieb | Bedienung | Bedienung | Werkstoff | Instandhaltung | Lebensdauer | Transport | Design | Design | Design | Design | Design | Design | Funktionen |  |  | Lager Flaschenöffnerplatte | Lager Gegenstück | Lagerausschub | Drehteller | Lager Gummiband | Robotterarm | Ausgabe Dayly M8 | Endproduktlager | Gehäuse | Elektronik | Software
 | A1 | A2 | A3 | A4 | A5 | A6 | A7 | A8 | A9 | A10 | A11 | A12 | A13 | A14 | A15 | A16 | A17 | A18 | A19 | A20 | A21 | A22 | A23 | A24 | A25 | A26 | A27 | A28 | A29 | A30 | A31 | A32 | A33 | A34
Gewichtung (aus Paarweisem Vergleich) | 8 | 8 | 9 | 2 | 10 | 10 | 10 | 10 | 10 | 10 | 7 | 5 | 8 | 2 | 10 | 6 | 9 | 8 | 8 | 3 | 10 | 10 | 2 | 2 | 2 | 6 | 6 | 2 | 2 | 2 | 7 | 2 | 2 | 7 | Gew. Summe | nomiert auf max. 10 | Bezeichnung |  |  |  |  |  |  |  |  |  |  |  | SUMME
Einfluss der Funktion auf die Spezifikation [3=sehr stark, 2=stark, 1=wenig; 0=keinen] |  |  |  |  |  |  |  |  |  |  |  |  |  |  |  |  |  |  |  |  |  |  |  |  |  |  |  |  |  |  |  |  |  |  | 0 | #DIV/0! | Lagerung Unterteile (Macsafe) |  |  |  |  |  |  |  |  |  |  |  | 0 | Einfluss der Funktion auf die Arbeitspakete [3=sehr stark, 2=stark, 1=wenig; 0=keinen]
 |  |  |  |  |  |  |  |  |  |  |  |  |  |  |  |  |  |  |  |  |  |  |  |  |  |  |  |  |  |  |  |  |  |  | 0 | #DIV/0! | Lagerung Oberteile (Tool) |  |  |  |  |  |  |  |  |  |  |  | 0
 |  |  |  |  |  |  |  |  |  |  |  |  |  |  |  |  |  |  |  |  |  |  |  |  |  |  |  |  |  |  |  |  |  |  | 0 | #DIV/0! | Ausschub Ober-/Unterteil |  |  |  |  |  |  |  |  |  |  |  | 0
 |  |  |  |  |  |  |  |  |  |  |  |  |  |  |  |  |  |  |  |  |  |  |  |  |  |  |  |  |  |  |  |  |  |  | 0 | #DIV/0! | Klemmen
 |  |  |  |  |  |  |  |  |  |  |  |  |  |  |  |  |  |  |  |  |  |  |  |  |  |  |  |  |  |  |  |  |  |  | 0 | #DIV/0! | Drehteller rotieren |  |  |  |  |  |  |  |  |  |  |  | 0
 |  |  |  |  |  |  |  |  |  |  |  |  |  |  |  |  |  |  |  |  |  |  |  |  |  |  |  |  |  |  |  |  |  |  |  |  | Lagerung Gummibänder
 |  |  |  |  |  |  |  |  |  |  |  |  |  |  |  |  |  |  |  |  |  |  |  |  |  |  |  |  |  |  |  |  |  |  | 0 | #DIV/0! | Gummilager verfahren |  |  |  |  |  |  |  |  |  |  |  | 0
 |  |  |  |  |  |  |  |  |  |  |  |  |  |  |  |  |  |  |  |  |  |  |  |  |  |  |  |  |  |  |  |  |  |  | 0 | #DIV/0! | Gummi auf Platten schieben |  |  |  |  |  |  |  |  |  |  |  | 0
 |  |  |  |  |  |  |  |  |  |  |  |  |  |  |  |  |  |  |  |  |  |  |  |  |  |  |  |  |  |  |  |  |  |  | 0 | #DIV/0! | Ablassen des Dayly M8
 |  |  |  |  |  |  |  |  |  |  |  |  |  |  |  |  |  |  |  |  |  |  |  |  |  |  |  |  |  |  |  |  |  |  | 0 | #DIV/0! | Ausgabe Dayly M8
 |  |  |  |  |  |  |  |  |  |  |  |  |  |  |  |  |  |  |  |  |  |  |  |  |  |  |  |  |  |  |  |  |  |  |  |  | (Lagerung Dayly M8)
 |  |  |  |  |  |  |  |  |  |  |  |  |  |  |  |  |  |  |  |  |  |  |  |  |  |  |  |  |  |  |  |  |  |  | 0 | #DIV/0! | Prozessüberwachung
 |  |  |  |  |  |  |  |  |  |  |  |  |  |  |  |  |  |  |  |  |  |  |  |  |  |  |  |  |  |  |  |  |  |  | 0 | #DIV/0! | Sicherheitsfunktion
 |  |  |  |  |  |  |  |  |  |  |  |  |  |  |  |  |  |  |  |  |  |  |  |  |  |  |  |  |  |  |  |  |  |  | 0 | #DIV/0! | Wartung
 |  |  |  |  |  |  |  |  |  |  |  |  |  |  |  |  |  |  |  |  |  |  |  |  |  |  |  |  |  |  |  |  |  |  |  |  | (Ausstellen)
 |  |  |  |  |  |  |  |  |  |  |  |  |  |  |  |  |  |  |  |  |  |  |  |  |  |  |  |  |  |  |  |  |  |  | 0 | #DIV/0! | Transport
SUMME | 0 | 0 | 0 | 0 | 0 | 0 | 0 | 0 | 0 | 0 | 0 | 0 | 0 | 0 | 0 | 0 | 0 | 0 | 0 | 0 | 0 | 0 | 0 | 0 | 0 | 0 | 0 | 0 | 0 | 0 | 0 | 0 | 0 | 0 |  |  |  | 0 | 0 | 0 | 0 | 0 | 0 | 0 | 0 | 0 | 0 | 0 |  | SUMME

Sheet: Erklärung der Funktionen
Nr. | Funktion | Beschreibung
 | Lagern von Unterteilen (Macsafe) | Bevorratung von Unterteilen in Magazin/Lager (10 Stück)
 | Lagern von Oberteilen (Tool) | Bevorratung von Oberteilen (ebenfalls 10 Stück)
 | Ausschub Unterteil | Lineareinheit bringt Unterteil auf den Drehteller
 | Klemmen | Festklemmen der Teile auf dem Drehteller
 | Drehteller rotieren | Neupositionierung des Drehtellers
 | Ausschub Oberteil | Oberteil wird auf das Unterteil geschoben
 | Gummilager verfahren | Das Lager mit den aufgezogenen Gummis (auf Vierkant) fährt in Position über die zusammengefügten Wallet-Platten.
 | Gummi vereinzeln | Mechanik/Roboterarm greift nur den vordersten Gummi (evtl. mit Führung oder Stopper).
 | Gummi auf Platten schieben | Roboterarm schiebt den Gummi axial vom Vierkant-Lager auf das Wallet – über beide Platten hinweg.
 | Ablassen des Dayly M8 | Fertiges Produkt wird fallen gelassen
 | Ausgabe Dayly M8 | Produkt wird weitertransportiert
 | Prozessüberwachung | Steuerung, Sensorik, Statusanzeigen
 | Sicherheitsfunktion | Not-Halt, Lichtschranke, Schutzverkleidung
 | Wartung ermöglichen | Zugang zu Lagern, Drehteller, Roboter etc.
 | Ausstellen | Ausstellen der Anlage auf Messen
 | Transport | Transport der Anlage

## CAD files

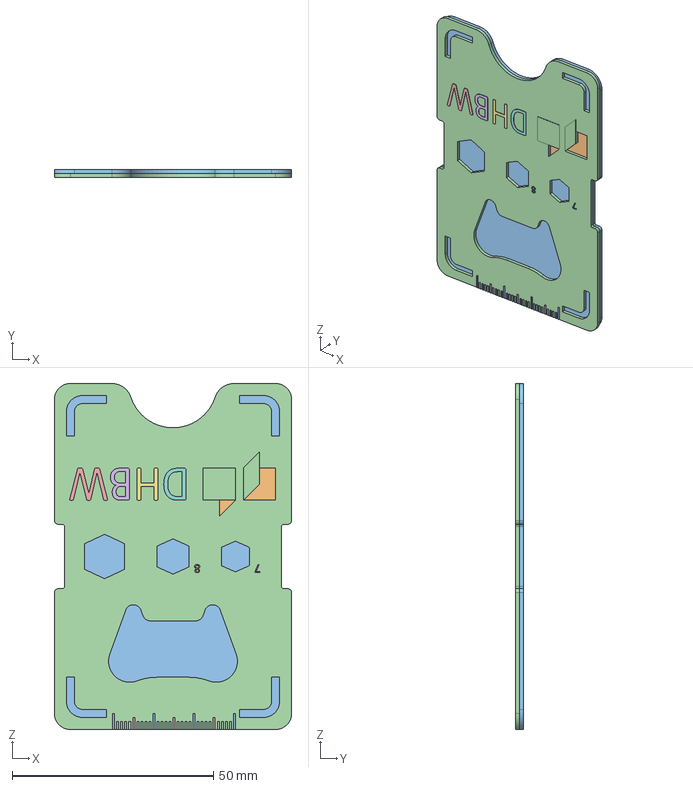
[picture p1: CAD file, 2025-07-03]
cad/giveaway/cad/giveaway_assembly.stp
59.0 x 2.10 x 86.0 mm
ROTE_SEITE
02_UNTERSEITE_MAGSAFE
01_OBERSEITE_TOOL_0040
01_OBERSEITE_TOOL_0041
01_OBERSEITE_TOOL_0042
01_OBERSEITE_TOOL_0043
01_OBERSEITE_TOOL_0044
01_OBERSEITE_TOOL_0045
01_OBERSEITE_TOOL_0046
01_OBERSEITE_TOOL_0047
01_OBERSEITE_TOOL_0048
01_OBERSEITE_TOOL_0049
01_OBERSEITE_TOOL_0050
01_OBERSEITE_TOOL_0051
01_OBERSEITE_TOOL_0052
01_OBERSEITE_TOOL_0053
01_OBERSEITE_TOOL_0054
01_OBERSEITE_TOOL_0055
01_OBERSEITE_TOOL_0056
01_OBERSEITE_TOOL_0057
01_OBERSEITE_TOOL_0058
01_OBERSEITE_TOOL_0059
01_OBERSEITE_TOOL_0060
01_OBERSEITE_TOOL_0061
01_OBERSEITE_TOOL_0062
01_OBERSEITE_TOOL_0063
01_OBERSEITE_TOOL_0064
01_OBERSEITE_TOOL_0065
01_OBERSEITE_TOOL_0066
01_OBERSEITE_TOOL_0067
01_OBERSEITE_TOOL_0068
01_OBERSEITE_TOOL_0069
01_OBERSEITE_TOOL_0070
01_OBERSEITE_TOOL_0071
01_OBERSEITE_TOOL_0072
01_OBERSEITE_TOOL_0073
01_OBERSEITE_TOOL_0074
01_OBERSEITE_TOOL_0075
01_OBERSEITE_TOOL_0076
01_OBERSEITE_TOOL_0077

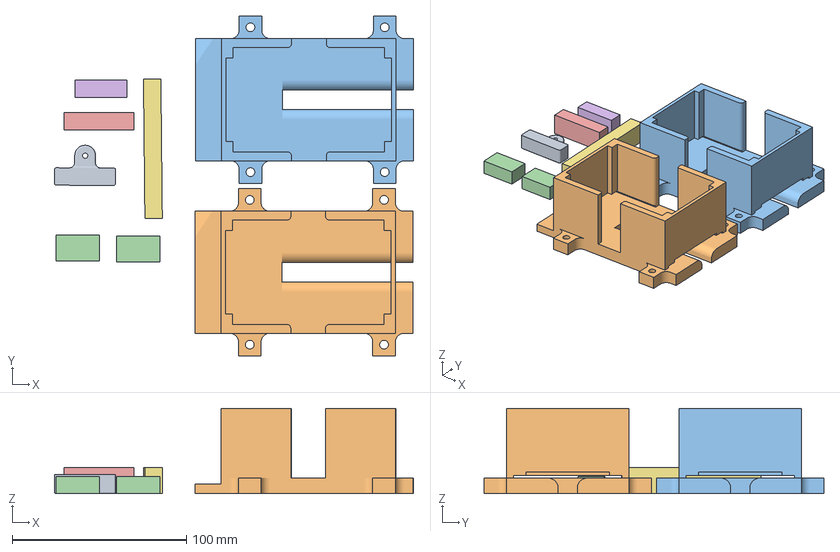
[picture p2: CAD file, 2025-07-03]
cad/3dprint/magazine.3mf
205.9 x 194.9 x 49.0 mm
Stempel_Solenoid.stp
Plattenmagazin_Tool (1).stp x 2
Magnethalterung_Wartungsklappe.stp
Anschlag_Robo_Auswurfbox_groß.stp
Anschlag_Robo_Auswurfbox.stp
Anschlag_Auswurfbox.stp

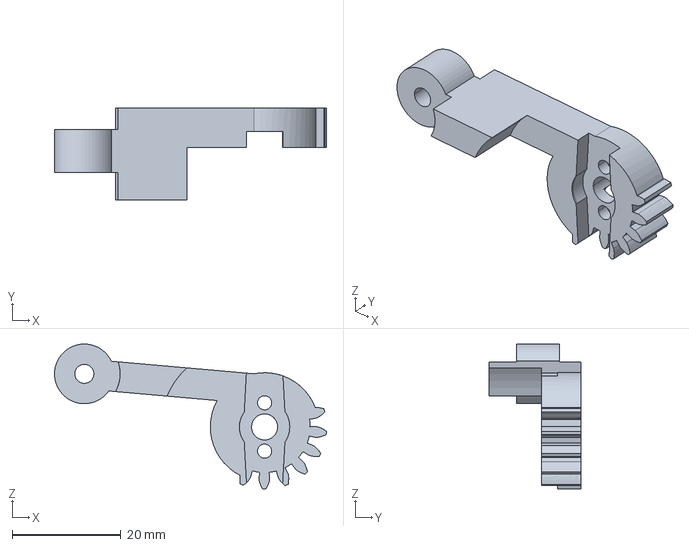
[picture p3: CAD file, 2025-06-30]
cad/robotarm/cad/zahnrad_rechts.stp
50.1 x 16.9 x 26.7 mm

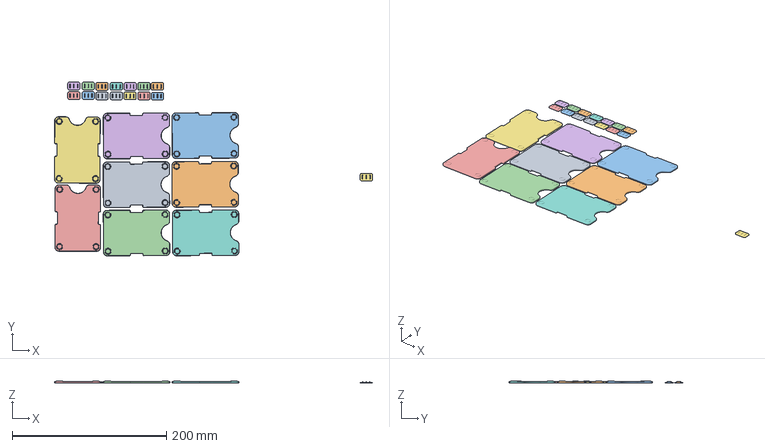
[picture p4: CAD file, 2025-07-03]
cad/3dprint/magsafeplate.3mf
412.6 x 225.6 x 3.20 mm
verschluss_asm.stp x 15
magsafeplatten_logo.stp x 8

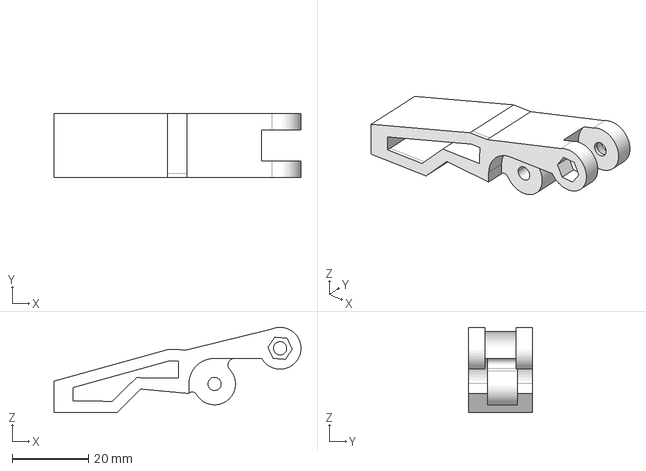
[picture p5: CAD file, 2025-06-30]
cad/robotarm/cad/greiferarm_rechts.stp
65.0 x 16.8 x 22.4 mm

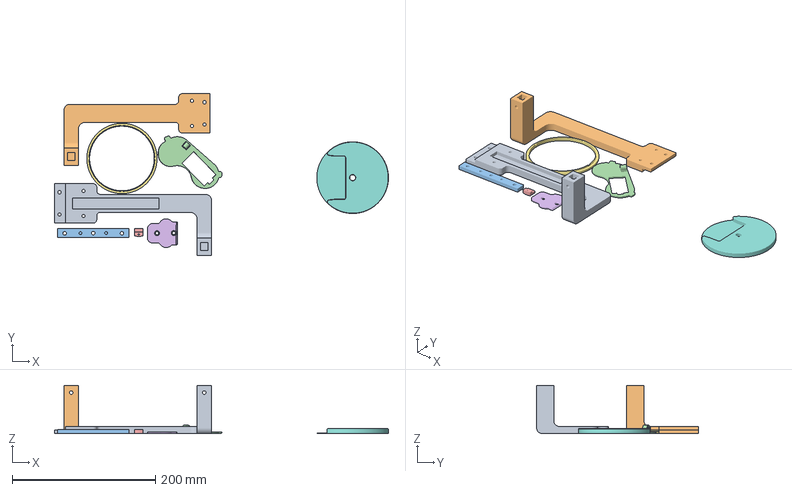
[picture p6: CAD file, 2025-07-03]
cad/3dprint/turntable.3mf
465.9 x 225.6 x 67.2 mm
Schlittenaufsatz_links_V1.stp
Schlittenaufsatz_rechts_V1.stp
neues_magazin_halterung.stp
s2-abdeckung.step
servosicherung.stp
Greiferabeckung.step
schleifring.stp
11_Drehscheibe.stp

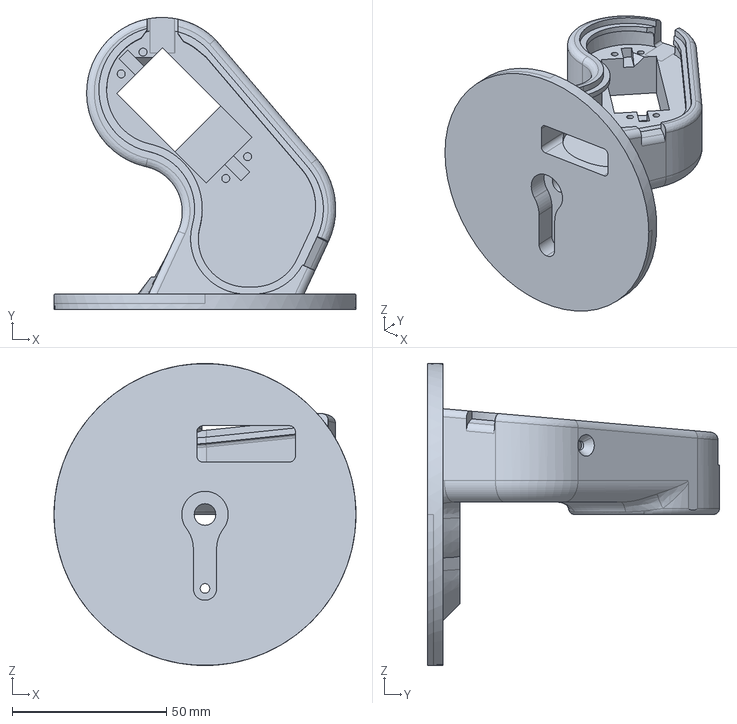
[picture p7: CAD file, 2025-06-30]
cad/robotarm/cad/basegelenk.stp
98.0 x 94.8 x 98.0 mm

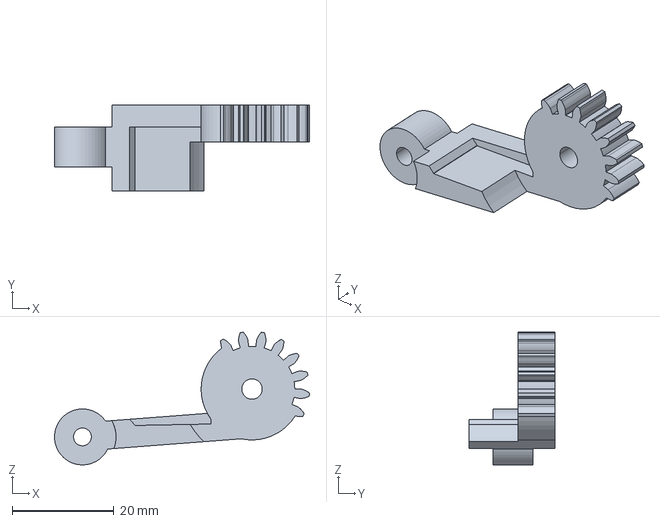
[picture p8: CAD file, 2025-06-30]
cad/robotarm/cad/zahnrad_links.stp
50.1 x 16.9 x 26.1 mm

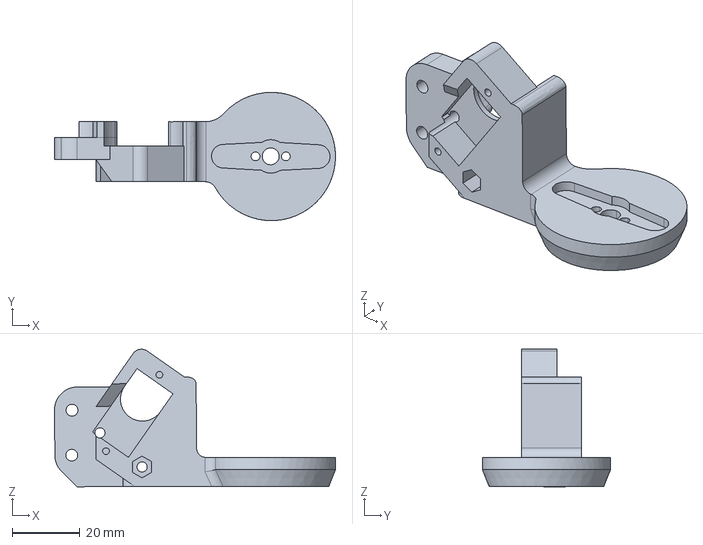
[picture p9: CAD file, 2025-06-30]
cad/robotarm/cad/greifergelenk_1.stp
83.2 x 38.0 x 40.8 mm

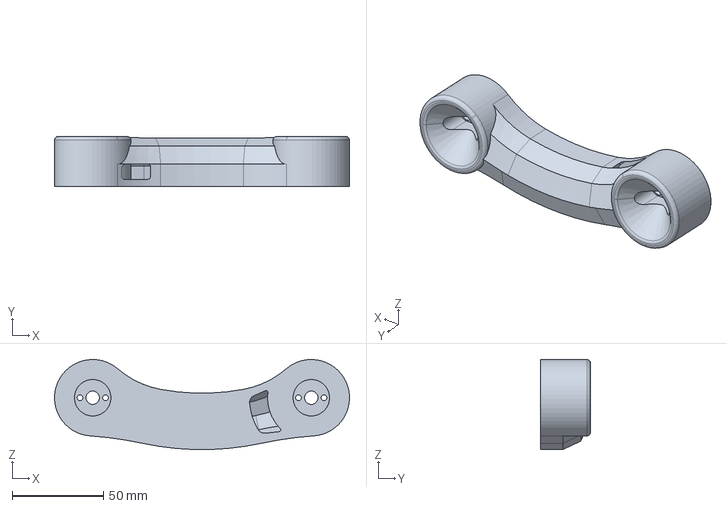
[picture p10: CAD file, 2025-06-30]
cad/robotarm/cad/mittelgelenk.stp
162.0 x 27.5 x 49.4 mm

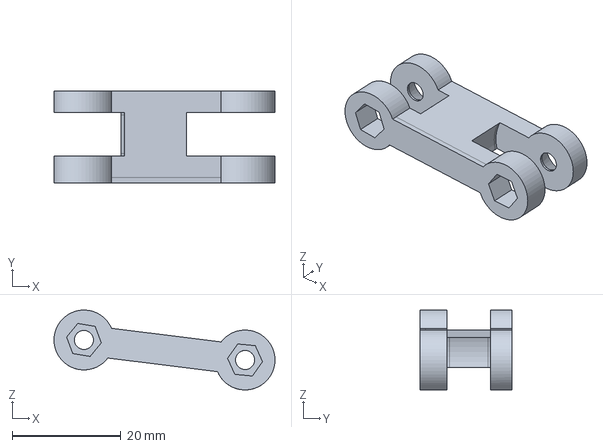
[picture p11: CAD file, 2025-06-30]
cad/robotarm/cad/umlenkung_rechts.stp
40.6 x 16.8 x 14.7 mm

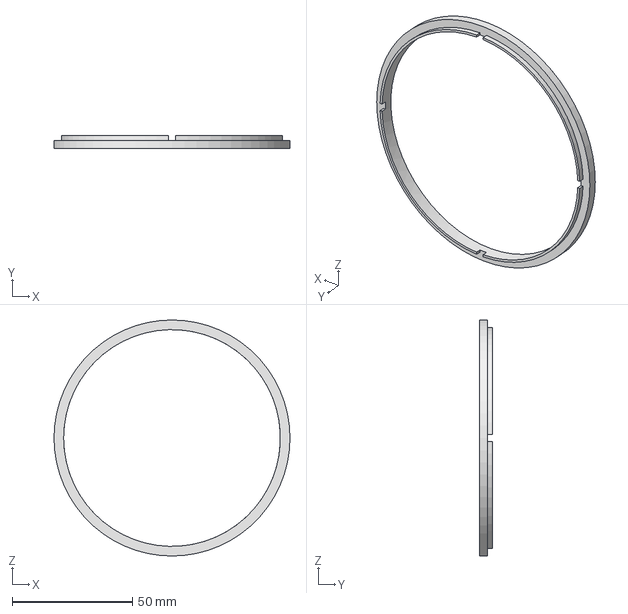
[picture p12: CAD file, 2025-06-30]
cad/robotarm/cad/schleifring.stp
98.0 x 5.20 x 98.0 mm

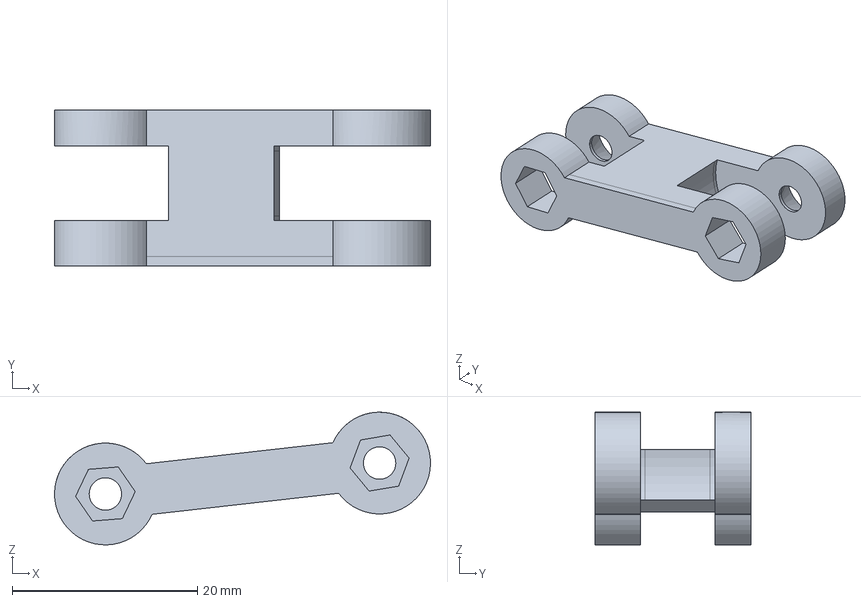
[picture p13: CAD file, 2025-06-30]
cad/robotarm/cad/umlenking_links.stp
40.6 x 16.8 x 14.3 mm

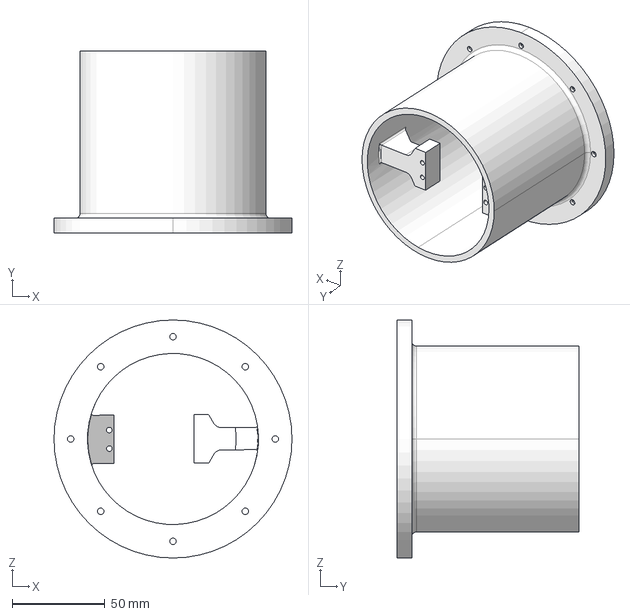
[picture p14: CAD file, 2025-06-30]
cad/robotarm/cad/base.stp
128.0 x 98.0 x 128.0 mm

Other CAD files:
cad/robotarm/cad/greifergelenk_2.stp
cad/robotarm/cad/servosicherung.stp
cad/robotarm/cad/greifergelenk.stp
cad/robotarm/cad/schiebebacke.stp

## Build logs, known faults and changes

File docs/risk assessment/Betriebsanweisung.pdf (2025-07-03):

Nummer: A | BETRIEBSANWEISUNG Betrieb: DailyM8
Bearbeitungsstand: | 06/25 Automatisierte Montageeinrichtung

### Arbeitsplatz/Tätigkeitsbereich: Maschinen- und Anlagenführer

## 1. ANWENDUNGSBEREICH

### Bedienen und Warten einer automatisieren Montageeinrichtung

## 2. GEFAHREN FÜR MENSCH UND UMWELT

- Benutzen der Anlage durch unbefugte Personen
- Quetschgefahr durch bewegende Teile
- Elektrische Gefährdung bei unsachgemäßer Wartung oder defekter Kabel
- Gefährdung durch Unsachgemäße Wartung – Risiko von Bedienfehlern
- Erhöhte Brandgefahr bei Kurzschlüssen oder defekten Netzteilen
- Lärmbelastung durch Antriebe und Mechanik
- Umweltbelastung durch falsche Entsorgung von Materialien

## 3. SCHUTZMAßNAHMEN UND VERHALTENSREGELN

- Die Montageeinrichtung darf nur von ausgebildeten Personen benutzt werden.
- Die Betriebsanleitung des DailyM8-Herstellers sind zu beachten.
- Nur geeignete Einzelbauteile bestimmungsgemäß verwenden.
- Die Montageeinrichtung darf nur mit gültigem Prüfnachweis (Plakette) verwendet werden.
- Regelmäßige Sichtkontrollen auf Beschädigungen und Abnutzung
- Vor dem Einsatz sind alle Schutzeinrichtungen zu prüfen: Stromanschluss, Endschalter und Not-Aus-Schalter
- Innerbetriebliche Sicherheitsregeln beachten.

## 4. VERHALTEN BEI STÖRUNGEN

- Bei sicherheitsrelevanten Störungen (z. B. an Elektrik, Programmierung, usw.) Montageeinrichtung sofort abstellen und Vorgesetzten informieren.
- Mängel nur vom Fachmann beseitigen lassen.

## 5. ERSTE HILFE

- Ersthelfer heranziehen
- Notruf: 112
- Unfall melden
- Durchgeführte Erste – Hilfe – Leistungen immer im Verbandsbuch eintragen

## 6. INSTANDHALTUNG

- Instandhaltung (Wartung, Reparatur) nur von qualifizierten und beauftragten Personen durchführen lassen.
- Bei der Instandhaltung die Betriebs- und Wartungsanleitung des Herstellers beachten.
- Wartung und Reinigung nur im ausgeschalteten und gesicherten Zustand durchführen
- Für die Entsorgung (z.B. Elektronikbauteile) ist zuständig:
Hannes Maurer
- Regelmäßige Prüfungen durch befähigte Personen.

________________________
Unterschrift:
Unternehmer/Geschäftsleitung

Datum: 05.06.2025

Nächster
Überprüfungstermin: 05.06.2026

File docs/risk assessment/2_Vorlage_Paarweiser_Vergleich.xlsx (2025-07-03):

 |  | Paarweiser Vergleich von (Kunden-) Anforderungen
Lfd. Nr. |  | Geometrie | Gewicht | Kosten | Ergonomie | Sicherheit | Sicherheit | Sicherheit | Sicherheit | Sicherheit | Elektrik | Zeit | Lagerkapazität | Antrieb | Energie | Bedienung | Bedienung | Werkstoff | Instandhaltung | Lebensdauer | Transport | Design | Design | Design | Design | Design | Design | Summe | Faktor, ganzzahlig, normiert auf 10 | Prozentwert, normiert
A1 | Geometrie |  | 1 | 1 | 2 | 0 | 1 | 2 | 1 | 2 | 2 | 1 | 1 | 1 | 2 | 2 | 2 | 2 | 2 | 2 | 2 | 2 | 2 | 1 | 2 | 2 | 1 | 39 | 8 | 6.0
A2 | Gewicht | 1 |  | 1 | 2 | 0 | 1 | 2 | 1 | 2 | 2 | 1 | 1 | 1 | 2 | 2 | 2 | 2 | 2 | 2 | 2 | 2 | 2 | 1 | 2 | 2 | 1 | 39 | 8 | 6.0
A3 | Kosten | 1 | 1 |  | 2 | 0 | 2 | 2 | 1 | 2 | 2 | 1 | 1 | 1 | 2 | 2 | 2 | 2 | 2 | 2 | 2 | 2 | 2 | 2 | 2 | 2 | 2 | 42 | 9 | 6.5
A4 | Ergonomie | 0 | 0 | 0 |  | 0 | 0 | 0 | 0 | 1 | 0 | 0 | 0 | 0 | 0 | 1 | 1 | 1 | 0 | 0 | 0 | 1 | 1 | 0 | 1 | 1 | 0 | 8 | 2 | 1.2
A9 | Sicherheit | 2 | 2 | 2 | 2 |  | 2 | 2 | 2 | 2 | 2 | 1 | 1 | 2 | 2 | 2 | 2 | 2 | 2 | 2 | 2 | 2 | 2 | 2 | 2 | 2 | 2 | 48 | 10 | 7.4
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

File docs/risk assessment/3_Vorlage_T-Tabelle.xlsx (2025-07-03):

 | Spezifikationen |  |  |  |  |  |  |  |  |  |  |  |  |  |  |  |  |  |  |  |  |  |  |  | Arbeitspakete
 | Antrieb | Geräuschpegel | Sicherheit | Leistung | Steuerung | Design | Ergonomie | Material | Geschwindigkeit | Flughöhe | Masse | Notfallsysmte | Sensorik | Navigation | EASA | Wartung | Klima- und Heizsystem | Batterieladung | Flugdynamik | Rotoranzahl | Bedienung | Funktionen |  |  | WP1 | WP2 | WP3 | ...
Gewichtung (aus Paarweisem Vergleich) | 10 | 10 | 10 | 10 | 10 | 0 | 3 | 3 | 7 | 10 | 6 | 10 | 9 | 8 | 10 | 6 | 1 | 7 |  |  |  | Gew. Summe | nomiert auf max. 10 | Bezeichnung |  |  |  |  |  |  |  |  |  |  |  | SUMME
Einfluss der Funktion auf die Spezifikation [3=sehr stark, 2=stark, 1=wenig; 0=keinen] | 2 | 3 | 2 | 2 | 3 | 0 | 0 | 0 | 3 | 2 | 2 | 1 | 1 | 1 | 3 | 2 | 1 | 2 | 3 | 3 | 0 | 257 | 10 | Flugfunktion |  |  |  |  |  |  |  |  |  |  |  |  | Einfluss der Funktion auf die Arbeitspakete [3=sehr stark, 2=stark, 1=wenig; 0=keinen]
 | 2 | 3 | 2 | 2 | 3 | 0 | 0 | 0 | 3 | 2 | 2 | 1 | 1 | 1 | 3 | 2 | 1 | 2 | 3 | 3 | 0 | 257 | 10 | Start- und Landungsfunktion
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

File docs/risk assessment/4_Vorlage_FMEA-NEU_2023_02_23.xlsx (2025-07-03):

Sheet: Intro
Die 6 1/2 Schritte einer Design-FMEA

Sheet: 1 Scope
Step 1: Scope
by definition/selection of scope of analysis, ensure consistent alignmnent and orientation!
Describe the project and create the project plan
Set analysis limits
integration of lessons learned from past
definition of team and team responsibility
collect whatever relevant data from available supporting sources
MR: diese Seite füllt d. Moderator

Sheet: 2 Structural analysis
Step 2: Structural Analysis
Determine the structure of the product (derivation from part list if necessary), e.g. Product> Assembly> Sub-Assembly> Components
Remark: Complex structures can be broken down into several structures (work packages) or different levels (block diagrams) and analyzed separately for organizational reasons or for deeper insights
Visualisation of the scope of analysis, e.g. Structure tree, block/demarcation diagrams, 3D models, scatches, etc.
Analysis of relationships, interfaces and interactions between defined system elements
Pre-selection of requirements/ functions/ components, use e.g. KANO, Pairwise comparison, QFD,..
Anm.: diese Seite füllt d. Konstrukteur aus
1st level | 2nd level | 3rd level | 4th level
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

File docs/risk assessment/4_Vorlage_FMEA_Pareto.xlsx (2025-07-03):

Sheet: Intro
Die 6 1/2 Schritte einer Design-FMEA

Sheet: 1 Scope
Step 1: Scope
by definition/selection of scope of analysis, ensure consistent alignmnent and orientation!
Describe the project and create the project plan
Set analysis limits
integration of lessons learned from past
definition of team and team responsibility
collect whatever relevant data from available supporting sources
MR: diese Seite füllt d. Moderator

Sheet: 2 Structural analysis
Step 2: Structural Analysis
Determine the structure of the product (derivation from part list if necessary), e.g. Product> Assembly> Sub-Assembly> Components
Remark: Complex structures can be broken down into several structures (work packages) or different levels (block diagrams) and analyzed separately for organizational reasons or for deeper insights
Visualisation of the scope of analysis, e.g. Structure tree, block/demarcation diagrams, 3D models, scatches, etc.
Analysis of relationships, interfaces and interactions between defined system elements
Pre-selection of requirements/ functions/ components, use e.g. KANO, Pairwise comparison, QFD,..
Anm.: diese Seite füllt d. Konstrukteur aus
1st level | 2nd level | 3rd level | 4th level
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

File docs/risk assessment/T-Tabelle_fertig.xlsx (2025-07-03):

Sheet: T-Tabelle
 | Spezifikationen |  |  |  |  |  |  |  |  |  |  |  |  |  |  |  |  |  |  |  |  |  |  |  |  |  |  |  |  |  |  |  |  |  |  |  |  | Baugruppen
 | Geometrie | Gewicht | Kosten | Ergonomie | Sicherheit | Sicherheit | Sicherheit | Sicherheit | Sicherheit | Sicherheit | Sicherheit | Sicherheit | Sicherheit | Sicherheit | Elektrik | Elektrik | Zeit | Lagerkapazität | Antrieb | Energie | Produktivität | Betrieb | Bedienung | Bedienung | Werkstoff | Instandhaltung | Lebensdauer | Transport | Design | Design | Design | Design | Design | Design | Funktionen |  |  | Lager Flaschenöffnerplatte | Lager Gegenstück | Lagerausschub | Drehteller | Lager Gummiband | Robotterarm | Ausgabe Dayly M8 | Gehäuse | Elektronik | Software | SUMME
 | A1 | A2 | A3 | A4 | A5 | A6 | A7 | A8 | A9 | A10 | A11 | A12 | A13 | A14 | A15 | A16 | A17 | A18 | A19 | A20 | A21 | A22 | A23 | A24 | A25 | A26 | A27 | A28 | A29 | A30 | A31 | A32 | A33 | A34
Gewichtung (aus Paarweisem Vergleich) | 8 | 8 | 9 | 2 | 10 | 10 | 10 | 10 | 10 | 10 | 7 | 5 | 8 | 2 | 10 | 6 | 9 | 8 | 8 | 3 | 10 | 10 | 2 | 2 | 2 | 6 | 6 | 2 | 2 | 2 | 7 | 2 | 2 | 7 | Gew. Summe | nomiert auf max. 10 | Bezeichnung
Einfluss der Funktion auf die Spezifikation [3=sehr stark, 2=stark, 1=wenig; 0=keinen] | 3 | 2 | 1 | 0 | 0 | 0 | 0 | 0 | 0 | 0 | 0 | 0 | 0 | 2 | 0 | 0 | 0 | 3 | 0 | 0 | 1 | 0 | 0 | 3 | 1 | 0 | 0 | 0 | 0 | 0 | 0 | 1 | 2 | 0 | 101 | 2 | Lagerung Unterteile (Macsafe) | 2 | 3 | 3 | 0 | 0 | 0 | 0 | 0 | 0 | 0 | 8 | Einfluss der Funktion auf die Arbeitspakete [3=sehr stark, 2=stark, 1=wenig; 0=keinen]
 | 3 | 2 | 1 | 0 | 0 | 0 | 0 | 0 | 0 | 0 | 0 | 0 | 0 | 2 | 0 | 0 | 0 | 3 | 0 | 0 | 1 | 0 | 0 | 3 | 1 | 0 | 0 | 0 | 0 | 0 | 0 | 1 | 2 | 0 | 101 | 2.337962963 | Lagerung Oberteile (Tool) | 3 | 2 | 3 | 0 | 0 | 0 | 0 | 0 | 0 | 0 | 8
 | 3 | 3 | 2 | 2 | 2 | 2 | 2 | 2 | 1 | 0 | 0 | 0 | 0 | 0 | 2 | 2 | 3 | 0 | 3 | 3 | 3 | 0 | 0 | 0 | 0 | 2 | 1 | 0 | 0 | 0 | 1 | 0 | 3 | 3 | 334 | 7.731481481 | Ausschub Ober-/Unterteil | 3 | 3 | 3 | 1 | 0 | 0 | 0 | 0 | 3 | 3 | 16
 | 1 | 2 | 2 | 1 | 1 | 2 | 2 | 2 | 1 | 0 | 0 | 0 | 0 | 0 | 2 | 1 | 1 | 0 | 2 | 3 | 3 | 1 | 0 | 0 | 0 | 2 | 1 | 0 | 0 | 0 | 3 | 0 | 2 | 2 | 281 | 6.50462963 | Klemmen | 0 | 0 | 0 | 2 | 0 | 0 | 2 | 0 | 3 | 3 | 10
 | 1 | 0 | 1 | 2 | 1 | 1 | 2 | 2 | 1 | 0 | 0 | 0 | 2 | 0 | 2 | 2 | 3 | 0 | 3 | 3 | 3 | 1 | 0 | 0 | 0 | 2 | 1 | 0 | 0 | 0 | 2 | 0 | 2 | 2 | 289 | 6.689814815 | Drehteller rotieren | 0 | 0 | 0 | 3 | 0 | 1 | 2 | 0 | 3 | 3 | 12
 | 3 | 2 | 1 | 0 | 0 | 0 | 0 | 0 | 0 | 0 | 0 | 0 | 0 | 2 | 0 | 0 | 0 | 3 | 0 | 0 | 1 | 0 | 0 | 3 | 1 | 0 | 0 | 0 | 0 | 0 | 0 | 1 | 1 | 0 | 99 | 2.291666667 | Lagerung Gummibänder | 0 | 0 | 0 | 0 | 3 | 0 | 0 | 0 | 0 | 0 | 3
 | 2 | 0 | 2 | 2 | 1 | 2 | 2 | 2 | 1 | 0 | 0 | 0 | 0 | 0 | 2 | 1 | 3 | 0 | 3 | 3 | 3 | 0 | 0 | 0 | 0 | 2 | 1 | 0 | 0 | 0 | 1 | 0 | 1 | 2 | 275 | 6.365740741 | Gummilager verfahren | 0 | 0 | 0 | 1 | 2 | 2 | 0 | 0 | 3 | 3 | 11
 | 3 | 2 | 3 | 2 | 2 | 2 | 2 | 2 | 1 | 0 | 0 | 0 | 1 | 0 | 2 | 2 | 3 | 1 | 3 | 3 | 3 | 0 | 0 | 0 | 0 | 2 | 1 | 0 | 1 | 0 | 1 | 0 | 2 | 3 | 351 | 8.125 | Gummi auf Platten schieben | 0 | 0 | 0 | 0 | 2 | 3 | 0 | 0 | 3 | 3 | 11
 | 2 | 1 | 0 | 2 | 0 | 0 | 0 | 1 | 0 | 0 | 0 | 0 | 1 | 0 | 0 | 0 | 2 | 0 | 1 | 1 | 2 | 1 | 0 | 0 | 0 | 0 | 0 | 0 | 0 | 0 | 0 | 0 | 0 | 0 | 105 | 2.430555556 | Ablassen des Daily M8 | 0 | 0 | 0 | 0 | 0 | 1 | 1 | 0 | 1 | 0 | 3
 | 1 | 0 | 1 | 1 | 3 | 3 | 2 | 2 | 2 | 3 | 2 | 0 | 0 | 0 | 0 | 0 | 1 | 0 | 1 | 2 | 2 | 3 | 0 | 0 | 0 | 0 | 0 | 0 | 1 | 2 | 3 | 1 | 0 | 2 | 299 | 6.921296296 | Ausgabe Daily M8 | 0 | 0 | 0 | 0 | 0 | 0 | 3 | 2 | 1 | 0 | 6
 | 1 | 1 | 3 | 0 | 1 | 1 | 3 | 3 | 3 | 0 | 0 | 0 | 0 | 0 | 3 | 2 | 0 | 2 | 1 | 2 | 1 | 1 | 3 | 3 | 0 | 1 | 0 | 0 | 0 | 1 | 0 | 0 | 0 | 2 | 279 | 6.458333333 | Prozessüberwachung | 0 | 0 | 0 | 1 | 0 | 2 | 1 | 0 | 3 | 3 | 10
 | 1 | 1 | 2 | 0 | 3 | 3 | 3 | 3 | 3 | 3 | 3 | 3 | 3 | 3 | 3 | 3 | 1 | 0 | 2 | 2 | 1 | 1 | 0 | 1 | 2 | 1 | 2 | 3 | 0 | 0 | 3 | 0 | 1 | 0 | 432 | 10 | Sicherheitsfunktion | 0 | 0 | 1 | 1 | 0 | 2 | 2 | 3 | 0 | 0 | 9
 | 1 | 0 | 0 | 0 | 3 | 3 | 3 | 1 | 1 | 1 | 3 | 1 | 1 | 0 | 0 | 2 | 0 | 0 | 1 | 2 | 2 | 0 | 1 | 0 | 1 | 3 | 3 | 0 | 0 | 1 | 1 | 0 | 3 | 0 | 263 | 6.087962963 | Wartung | 1 | 1 | 2 | 1 | 1 | 3 | 0 | 1 | 0 | 0 | 10
 | 2 | 0 | 0 | 3 | 0 | 0 | 2 | 2 | 1 | 1 | 3 | 1 | 1 | 0 | 0 | 0 | 2 | 0 | 0 | 2 | 3 | 3 | 3 | 3 | 1 | 0 | 0 | 1 | 3 | 3 | 0 | 3 | 0 | 3 | 255 | 5.902777778 | Ausstellungsattraktivität | 1 | 1 | 2 | 2 | 1 | 3 | 1 | 2 | 2 | 2 | 17
 | 3 | 3 | 0 | 0 | 0 | 0 | 0 | 0 | 0 | 0 | 3 | 2 | 3 | 3 | 0 | 2 | 0 | 0 | 0 | 0 | 0 | 0 | 0 | 0 | 2 | 0 | 0 | 3 | 0 | 0 | 2 | 0 | 2 | 0 | 149 | 3.449074074 | Transport | 0 | 0 | 0 | 0 | 0 | 1 | 0 | 3 | 0 | 0 | 4
SUMME | 30 | 19 | 19 | 15 | 17 | 19 | 23 | 22 | 15 | 8 | 14 | 7 | 12 | 12 | 16 | 17 | 19 | 12 | 20 | 26 | 29 | 11 | 7 | 16 | 9 | 15 | 10 | 7 | 5 | 7 | 15 | 7 | 19 | 19 |  |  |  | 10 | 10 | 14 | 12 | 9 | 18 | 12 | 11 | 22 | 20 |  | SUMME

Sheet: Erklärung der Funktionen
Nr. | Funktion | Beschreibung
 | Lagern von Unterteilen (Macsafe) | Bevorratung von Unterteilen in Magazin/Lager (10 Stück)
 | Lagern von Oberteilen (Tool) | Bevorratung von Oberteilen (ebenfalls 10 Stück)
 | Ausschub Unterteil | Lineareinheit bringt Unterteil auf den Drehteller
 | Klemmen | Festklemmen der Teile auf dem Drehteller
 | Drehteller rotieren | Neupositionierung des Drehtellers
 | Ausschub Oberteil | Oberteil wird auf das Unterteil geschoben
 | Gummilager verfahren | Das Lager mit den aufgezogenen Gummis (auf Vierkant) fährt in Position über die zusammengefügten Wallet-Platten.
 | Gummi vereinzeln | Mechanik/Roboterarm greift nur den vordersten Gummi (evtl. mit Führung oder Stopper).
 | Gummi auf Platten schieben | Roboterarm schiebt den Gummi axial vom Vierkant-Lager auf das Wallet – über beide Platten hinweg.
 | Ablassen des Dayly M8 | Fertiges Produkt wird fallen gelassen
 | Ausgabe Dayly M8 | Produkt wird weitertransportiert
 | Prozessüberwachung | Steuerung, Sensorik, Statusanzeigen
 | Sicherheitsfunktion | Not-Halt, Lichtschranke, Schutzverkleidung
 | Wartung ermöglichen | Zugang zu Lagern, Drehteller, Roboter etc.
 | Ausstellungsattraktivität | Ausstellen der Anlage auf Messen
 | Transport | Transport der Anlage

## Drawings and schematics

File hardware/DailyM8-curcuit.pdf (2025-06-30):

1 | 2 | 3 | 4 | 5 | 6 | 7 | 8

A

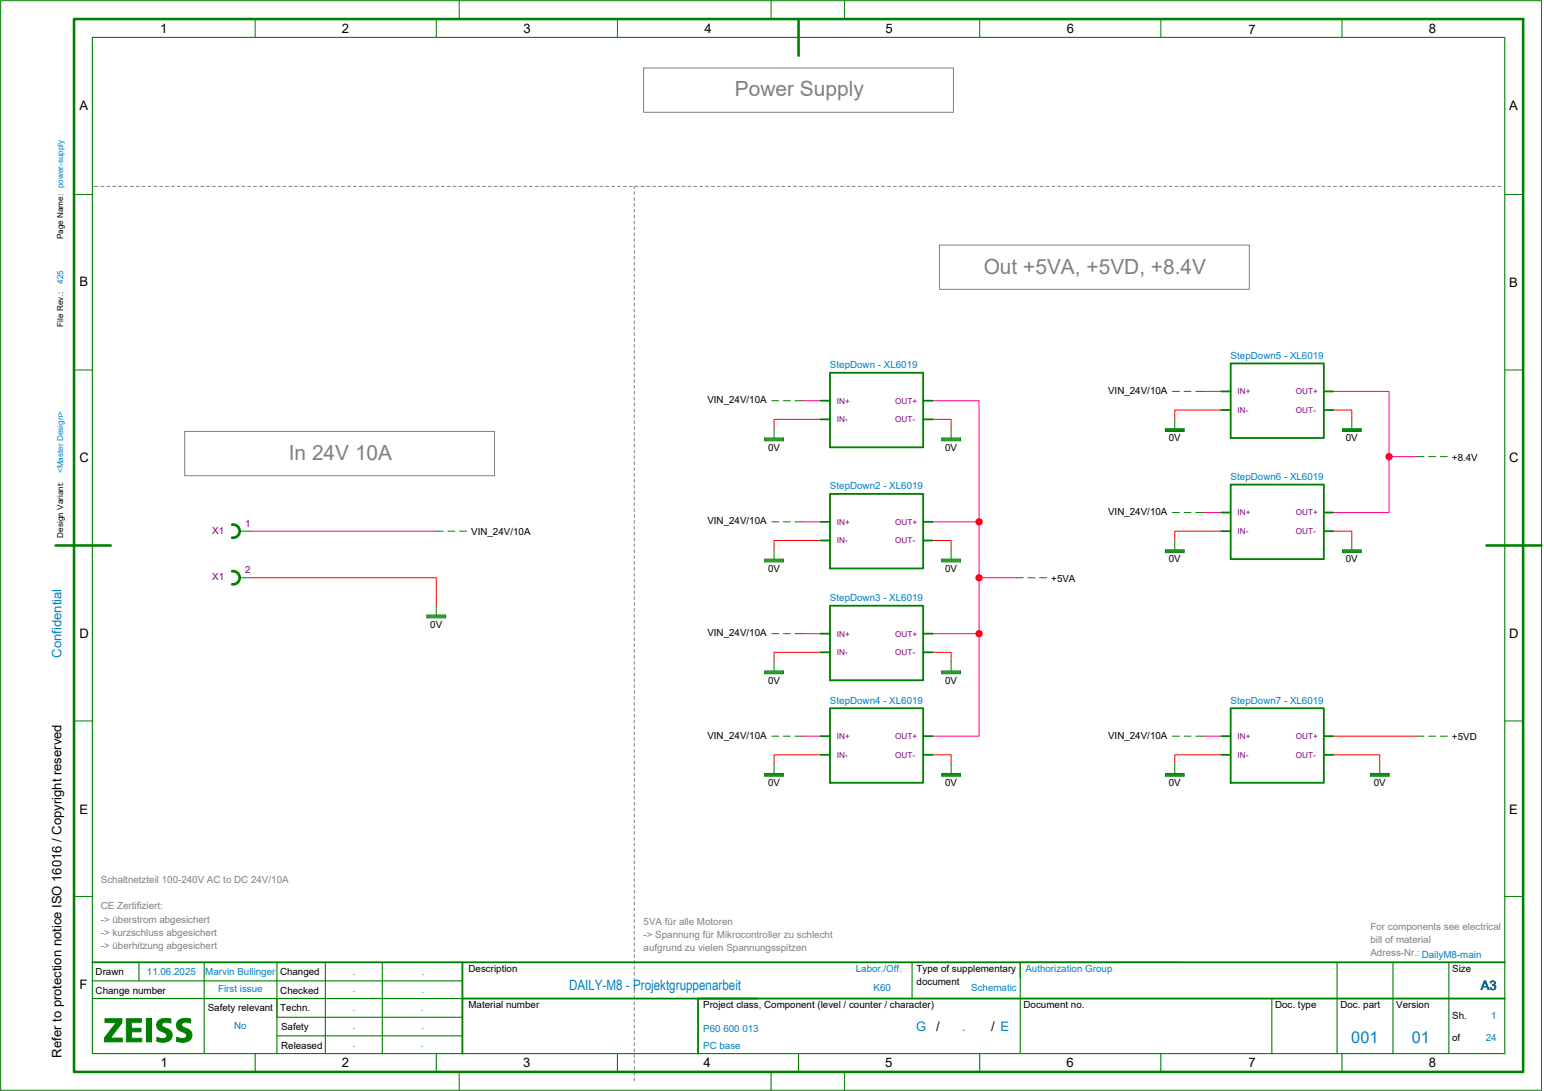
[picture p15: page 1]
Description; Type of supplementary; document; Drawn; Changed; Size; A3 Change number; Checked; Safety relevant; Techn.; Material number; Project class, Component (level / counter / character); Document no.; Safety; Released; Doc. type; Doc. part; Version; DAILY-M8 - Projektgruppenarbeit; Marvin Bullinger; PC base; Schematic; First issue; . <Master Design> 425 power-supply; Confidential; Labor./Off.; Authorization Group; VIN_24V/10A; OUT+; OUT-; StepDown - XL6019; StepDown2 - XL6019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

Design Variant: File Rev.: Page Name:

Refer to protection notice ISO 16016 / Copyright reserved

Schaltnetzteil 100-240V AC to DC 24V/10A

5VA für alle Motoren
-> Spannung für Mikrocontroller zu schlecht

For components see electrical
bill of material
Adress-Nr.:

A

A

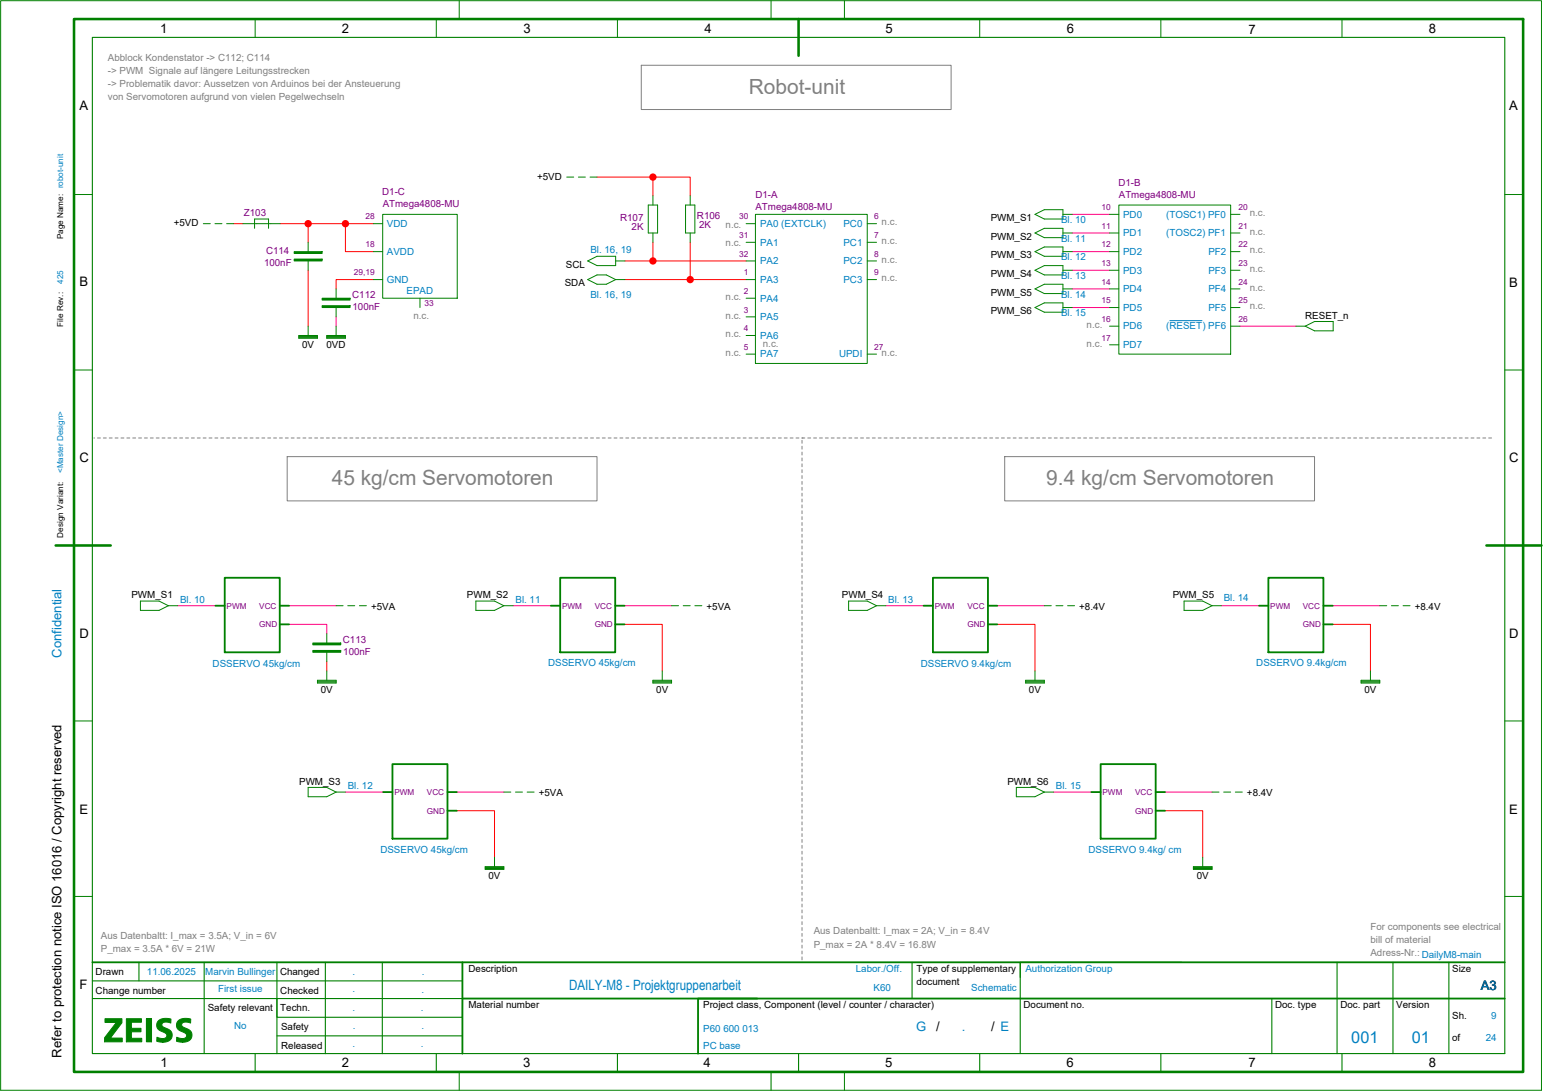
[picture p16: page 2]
PA0 (EXTCLK); UPDI; ATmega4808-MU; (TOSC1) PF0; (TOSC2) PF1; (RESET) PF6; D1-B ATmega4808-MU; VDD; EPAD; AVDD; GND; D1-C ATmega4808-MU; Description; Type of supplementary; document; Drawn; Changed; Size; A3 Change number; Checked; DAILY-M8 - Projektgruppenarbeit; Marvin Bullinger; Schematic; First issue; . <Master Design> 425 robot-unit; Confidential; Labor./Off.; Authorization Group; SCL; SDA; RESET_n; PWM_S1; PWM_S2; PWM_S3; PWM_S4; PWM_S5; PWM_S6; PWM_S1 Bl. 10; PWM_S2 Bl. 11; PWM_S3 Bl. 12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

Abblock Kondenstator -> C112; C114
-> PWM Signale auf längere Leitungsstrecken
-> Problematik davor: Aussetzen von Arduinos bei der Ansteuerung
von Servomotoren aufgrund von vielen Pegelwechseln

Design Variant: File Rev.: Page Name:

Refer to protection notice ISO 16016 / Copyright reserved

For components see electrical
bill of material
Adress-Nr.:

A

A

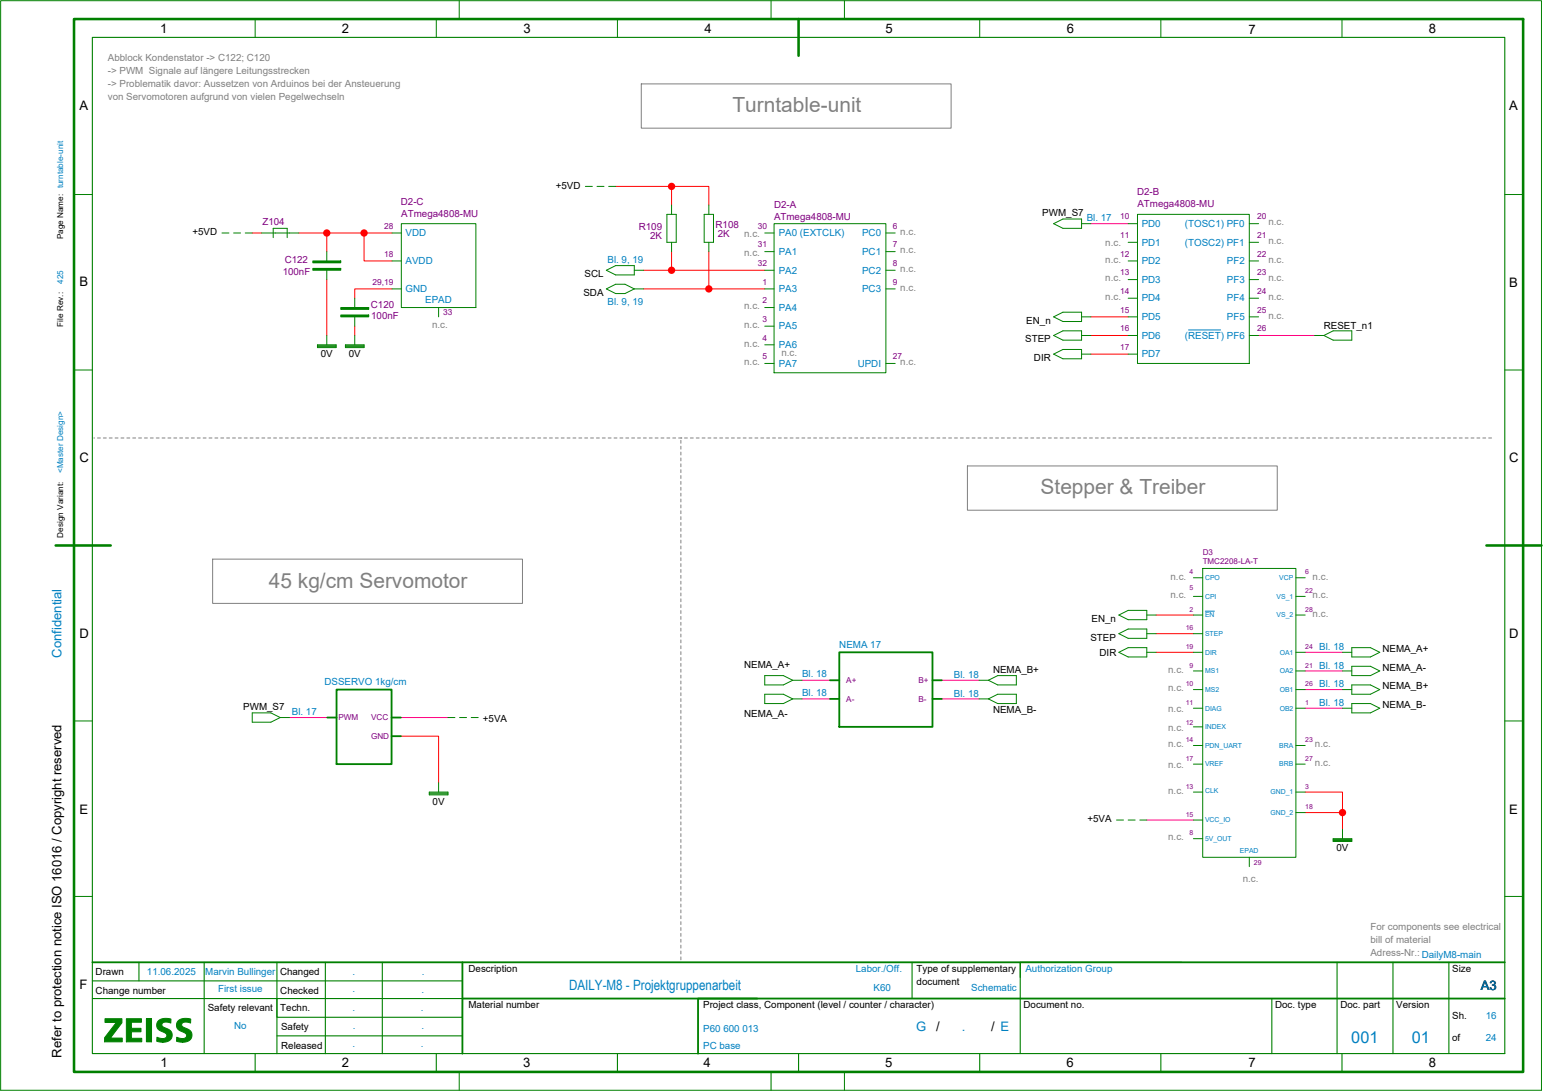
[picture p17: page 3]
PA0 (EXTCLK); UPDI; ATmega4808-MU; (TOSC1) PF0; (TOSC2) PF1; (RESET) PF6; D2-B ATmega4808-MU; VDD; EPAD; AVDD; GND; D2-C ATmega4808-MU; GND_1; CPO; CPI; VCP; 5V_OUT; DIAG; INDEX; CLK; PDN_UART; VCC_IO; STEP; VREF; GND_2; DIR; BRA; BRB; D3 TMC2208-LA-T; Description; Type of supplementary; document; Drawn; Changed; Size; A3 Change number; Checked; DAILY-M8 - Projektgruppenarbeit; Marvin Bullinger; Schematic; First issue; . <Master Design> 425 turntable⁻unit; Confidential; Labor./Off.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

Abblock Kondenstator -> C122; C120
-> PWM Signale auf längere Leitungsstrecken
-> Problematik davor: Aussetzen von Arduinos bei der Ansteuerung

Design Variant: File Rev.: Page Name:

45 kg/cm Servomotor

Refer to protection notice ISO 16016 / Copyright reserved

For components see electrical
bill of material
Adress-Nr.:

A

A

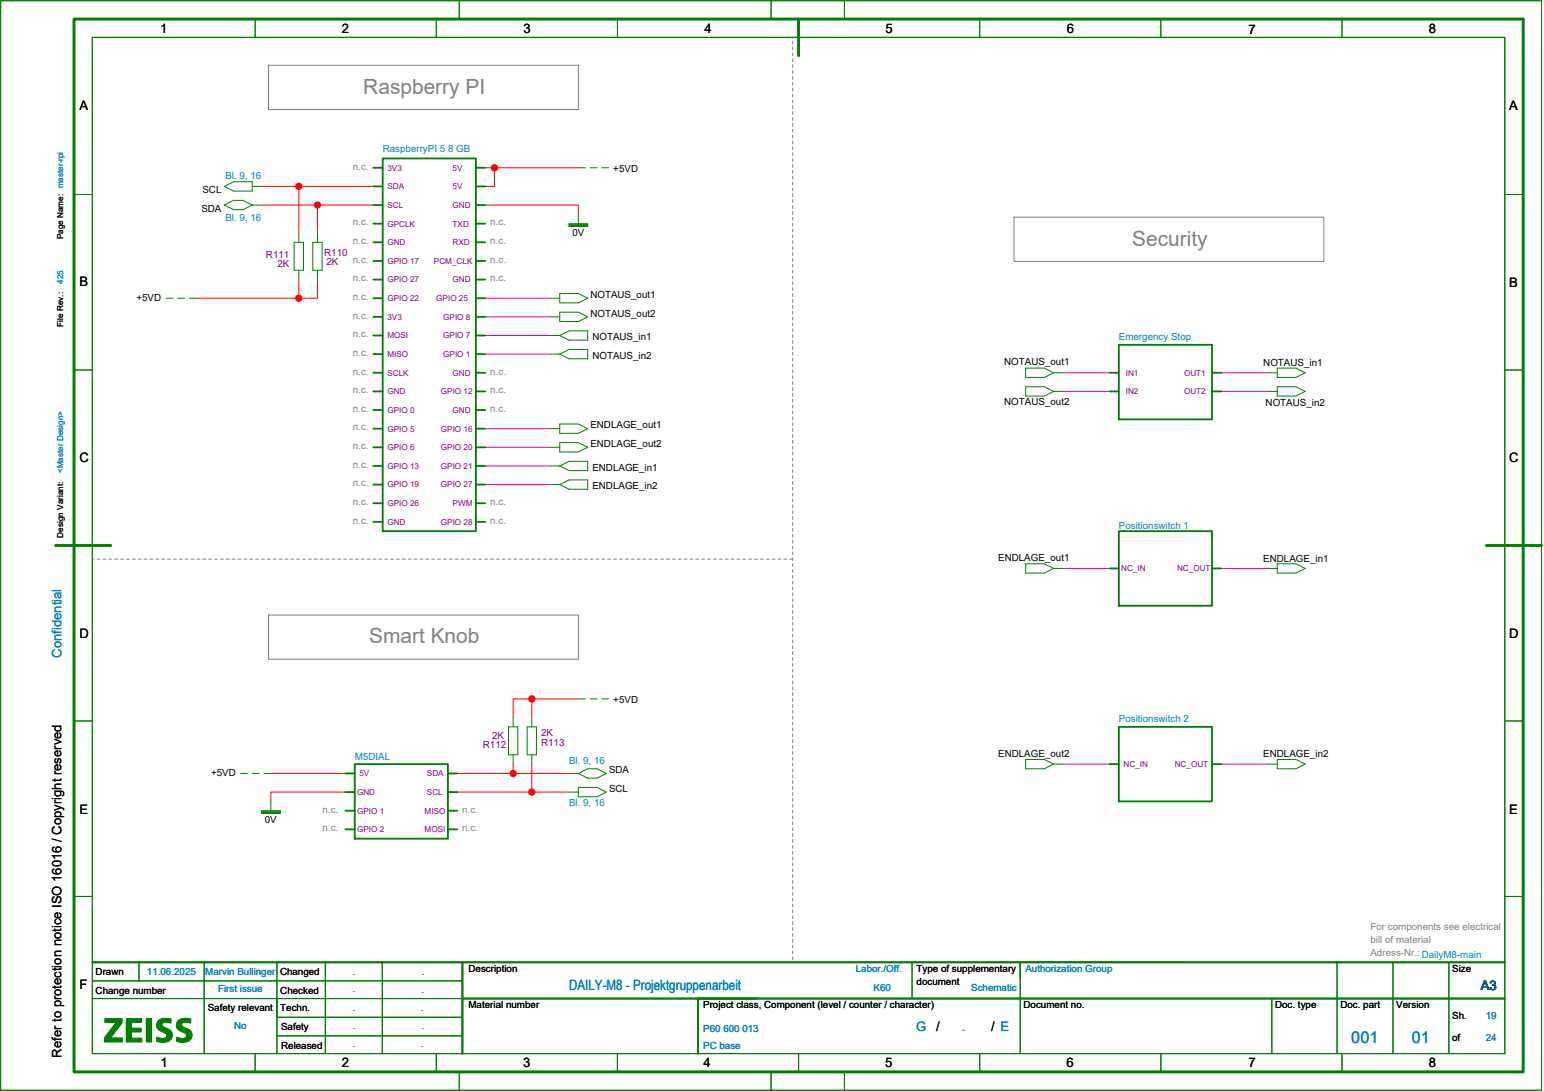
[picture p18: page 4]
Description; Type of supplementary; document; Drawn; Changed; Size; A3 Change number; Checked; DAILY-M8 - Projektgruppenarbeit; Marvin Bullinger; Schematic; First issue; . <Master Design> 425 master-rpi; Confidential; Labor./Off.; Authorization Group; SCL; SDA; NOTAUS_out1; NOTAUS_out2; ENDLAGE_out1; ENDLAGE_out2; NOTAUS_in1; NOTAUS_in2; ENDLAGE_in1; ENDLAGE_in2; GPCLK; GND; GPIO 17; GPIO 27; GPIO 22; MOSI; MISO; SCLK; GPIO 0; GPIO 5; GPIO 6; GPIO 13; GPIO 19; GPIO 26; TXD; RXD; PCM_CLK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

Design Variant: File Rev.: Page Name:

Refer to protection notice ISO 16016 / Copyright reserved

For components see electrical
bill of material
Adress-Nr.:

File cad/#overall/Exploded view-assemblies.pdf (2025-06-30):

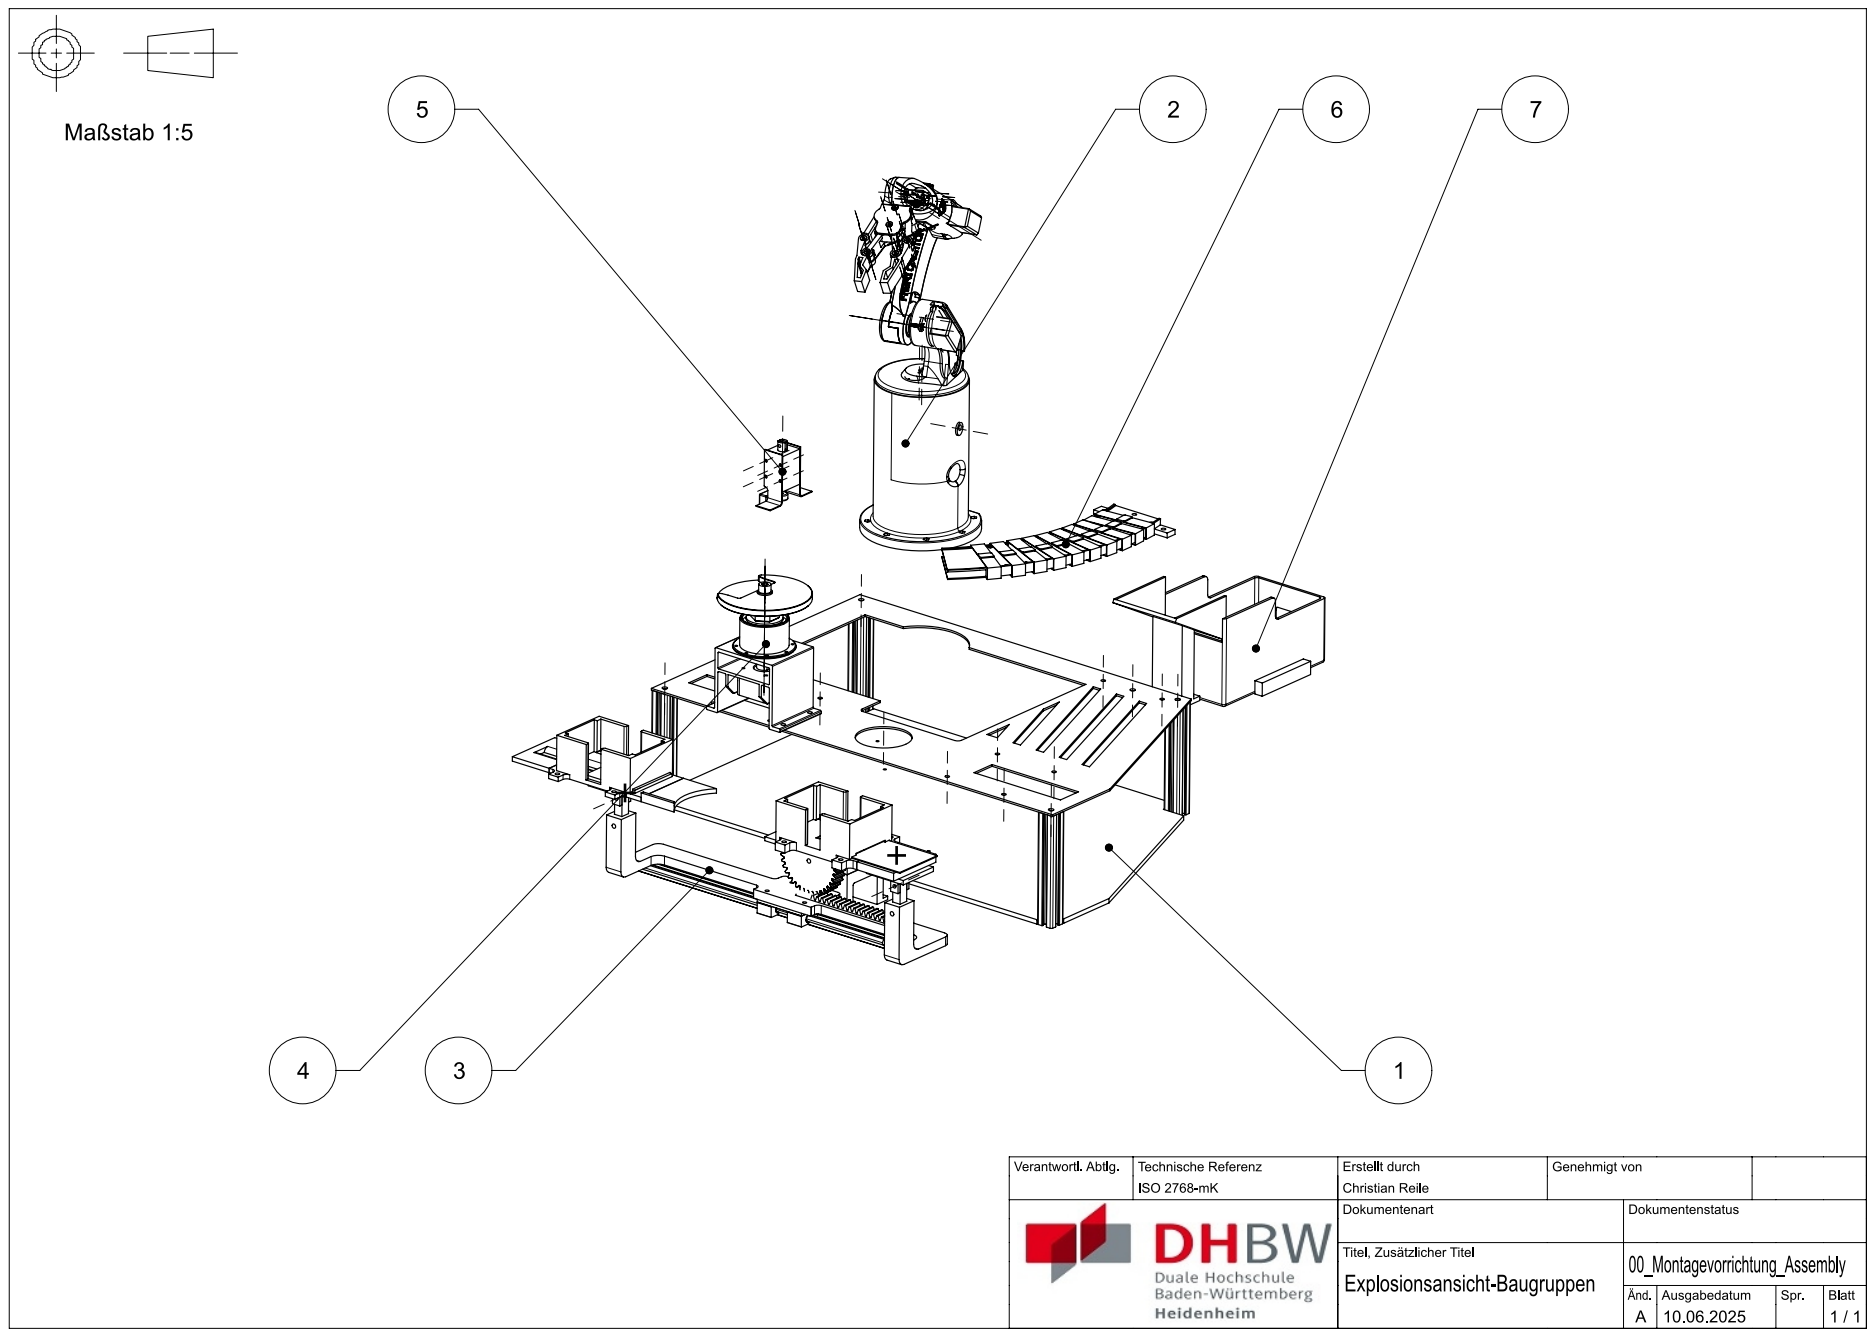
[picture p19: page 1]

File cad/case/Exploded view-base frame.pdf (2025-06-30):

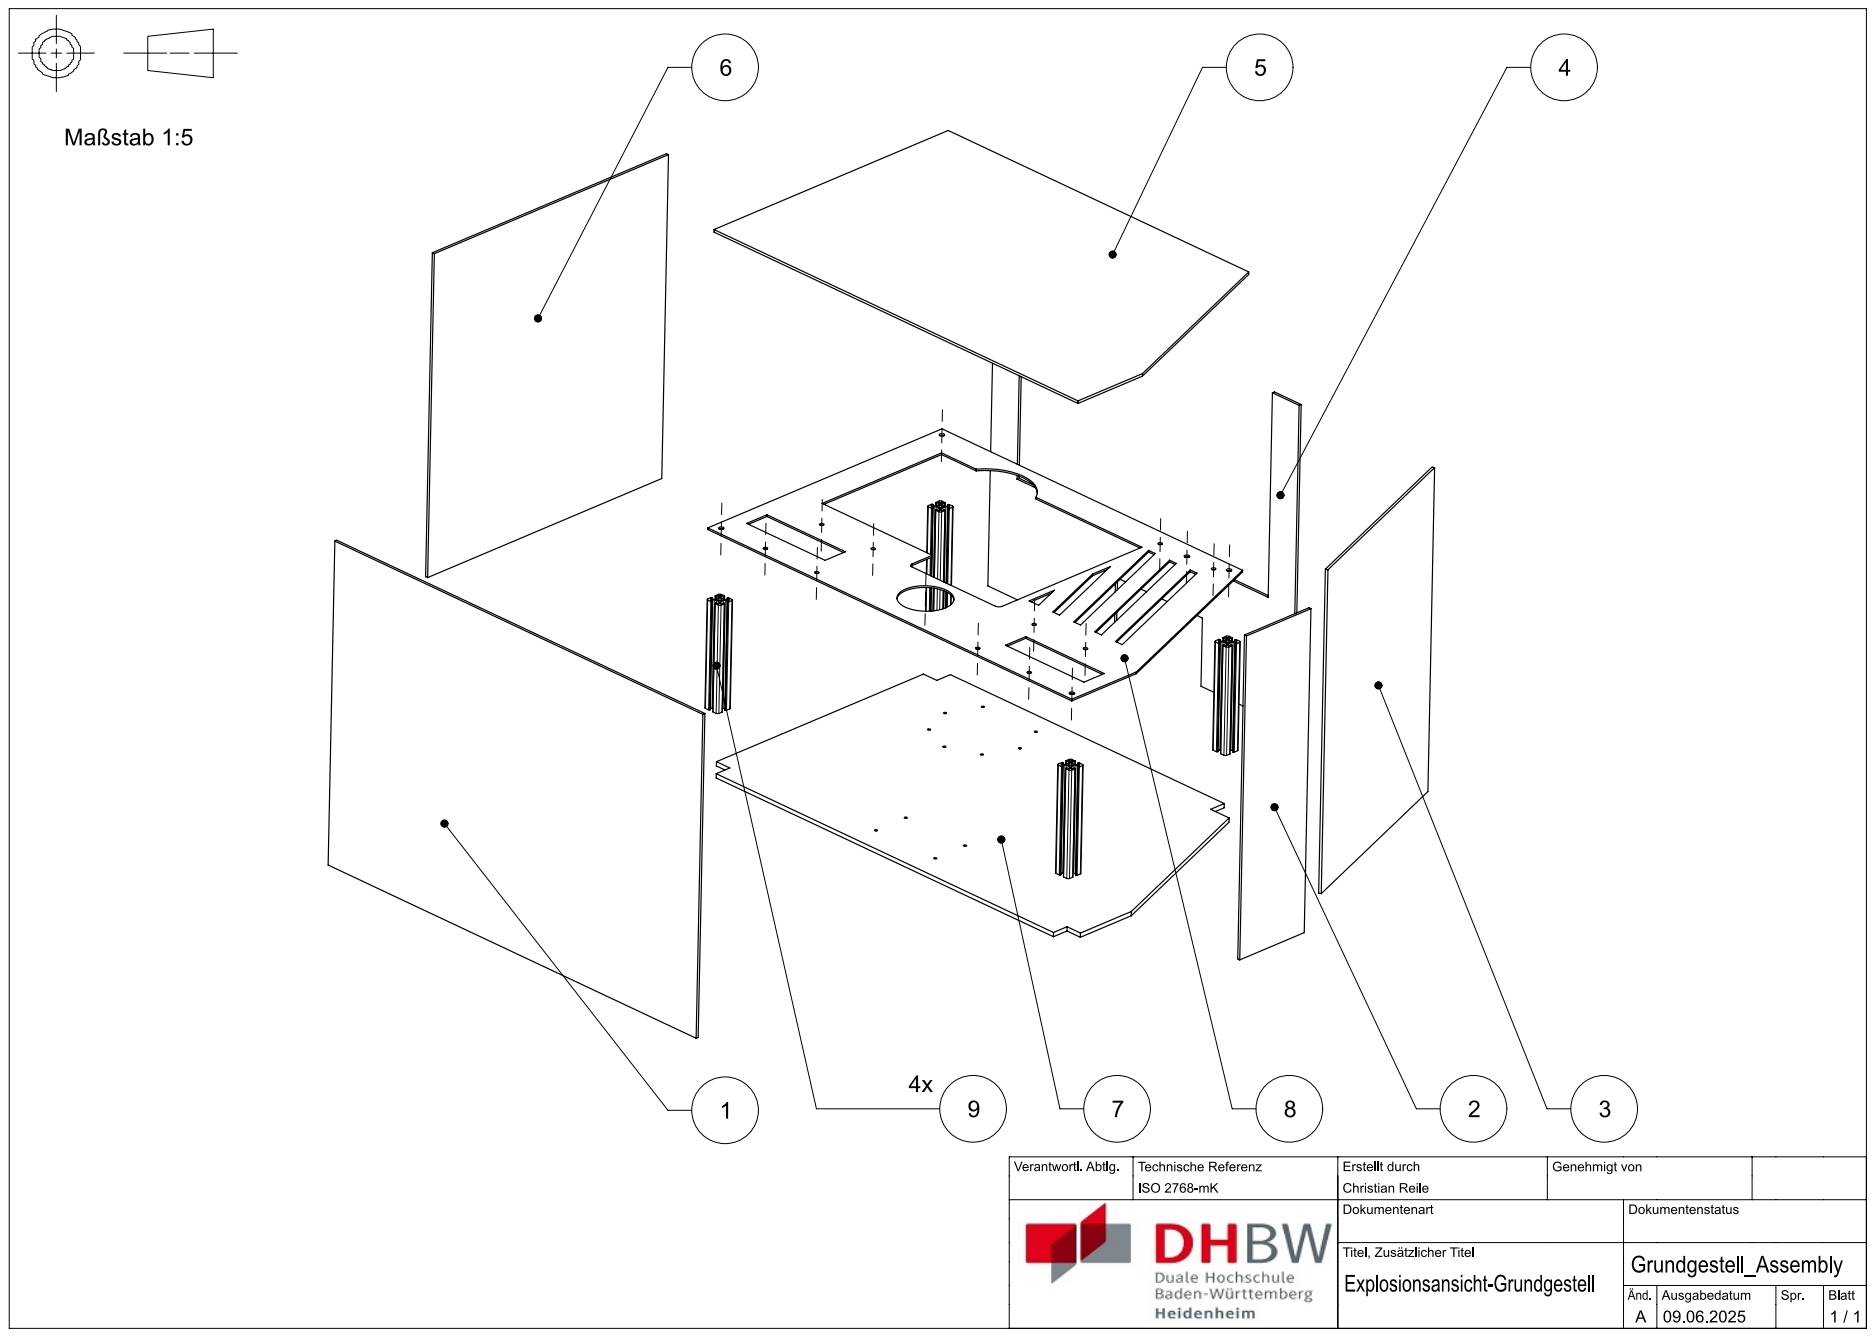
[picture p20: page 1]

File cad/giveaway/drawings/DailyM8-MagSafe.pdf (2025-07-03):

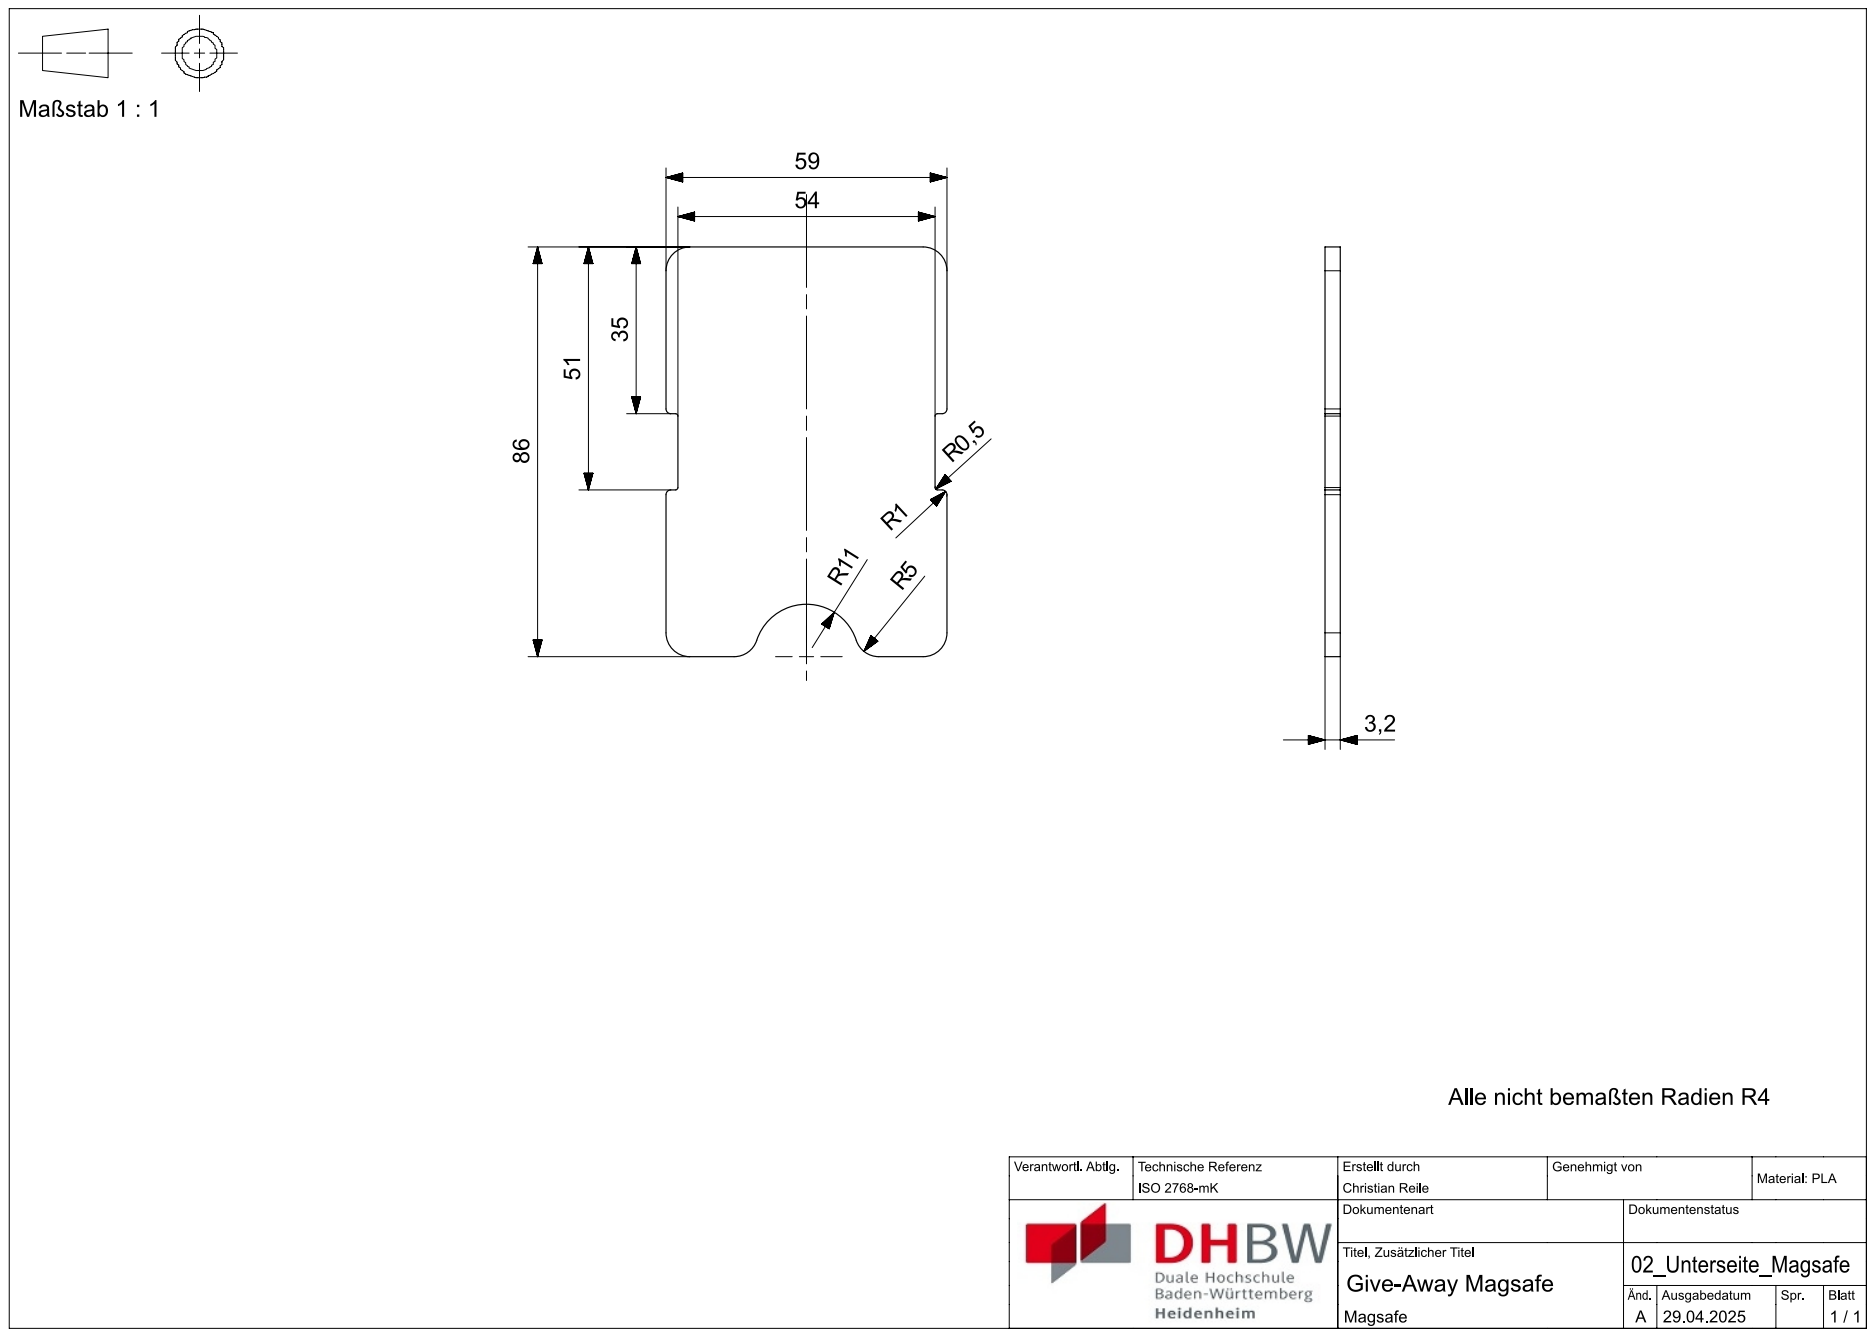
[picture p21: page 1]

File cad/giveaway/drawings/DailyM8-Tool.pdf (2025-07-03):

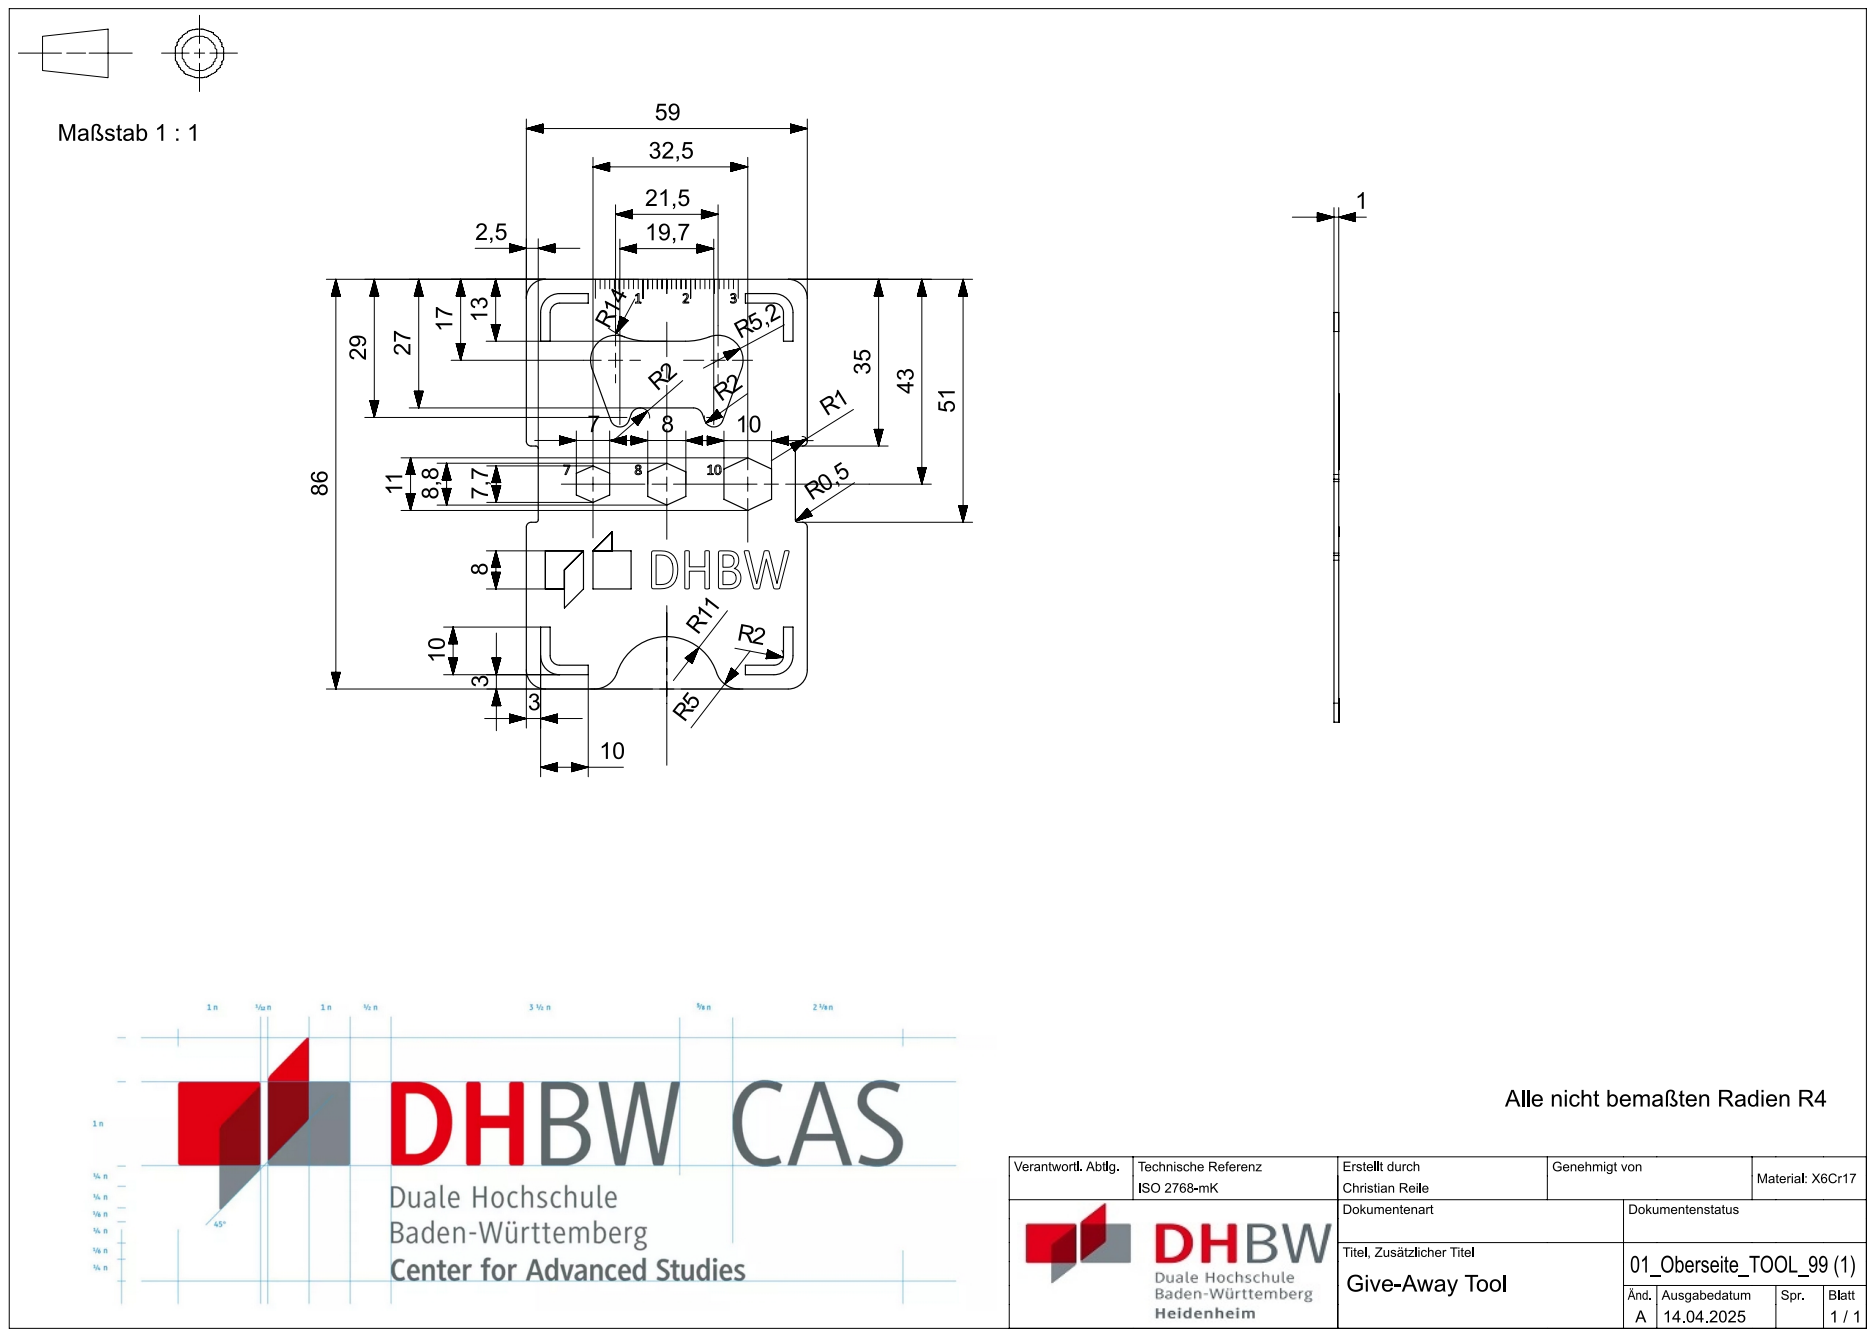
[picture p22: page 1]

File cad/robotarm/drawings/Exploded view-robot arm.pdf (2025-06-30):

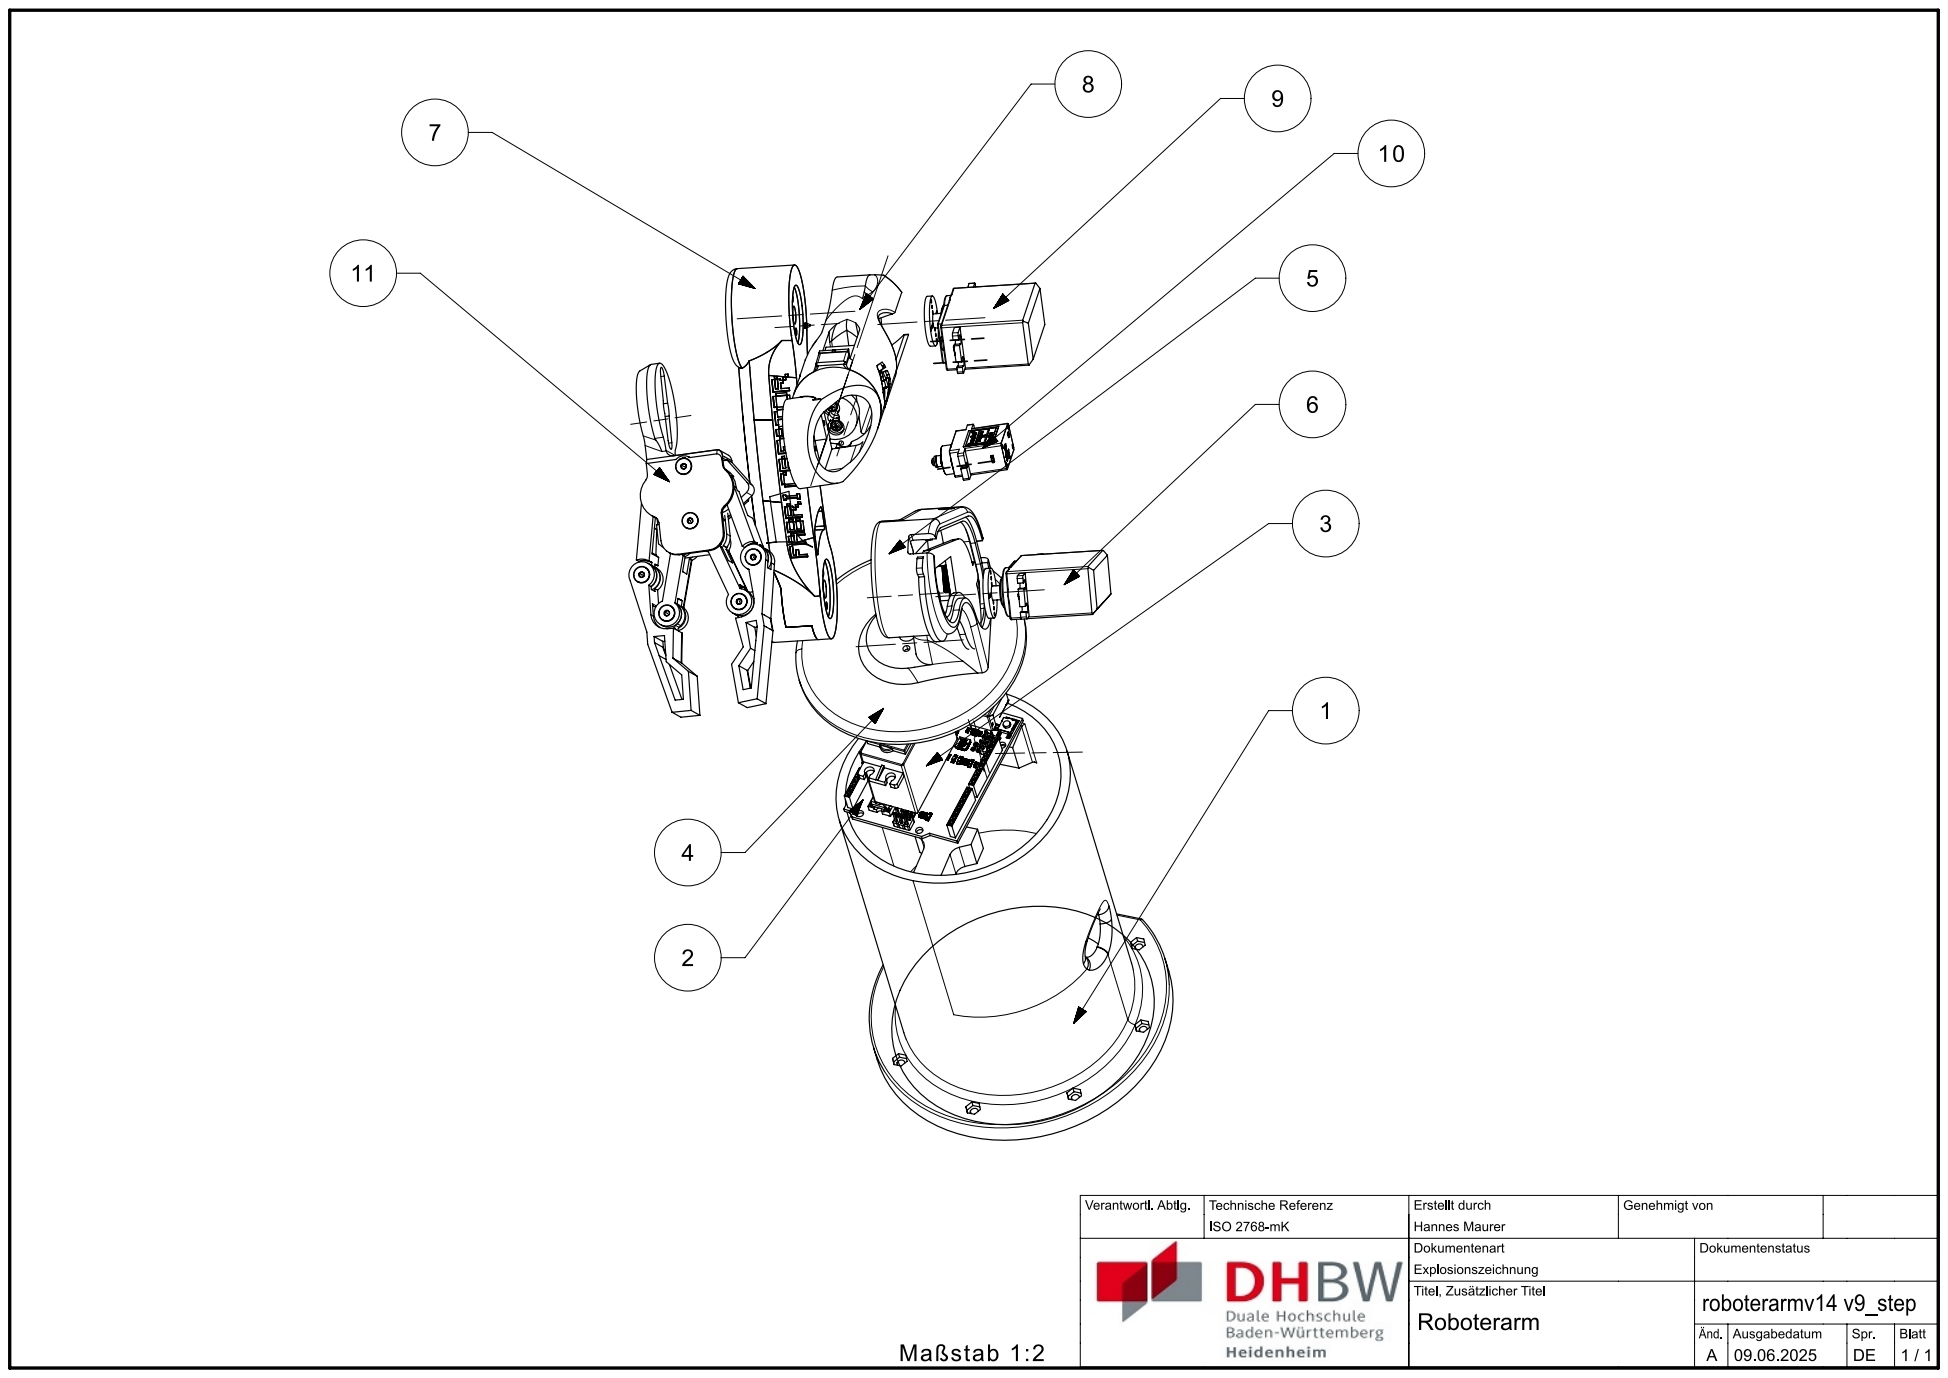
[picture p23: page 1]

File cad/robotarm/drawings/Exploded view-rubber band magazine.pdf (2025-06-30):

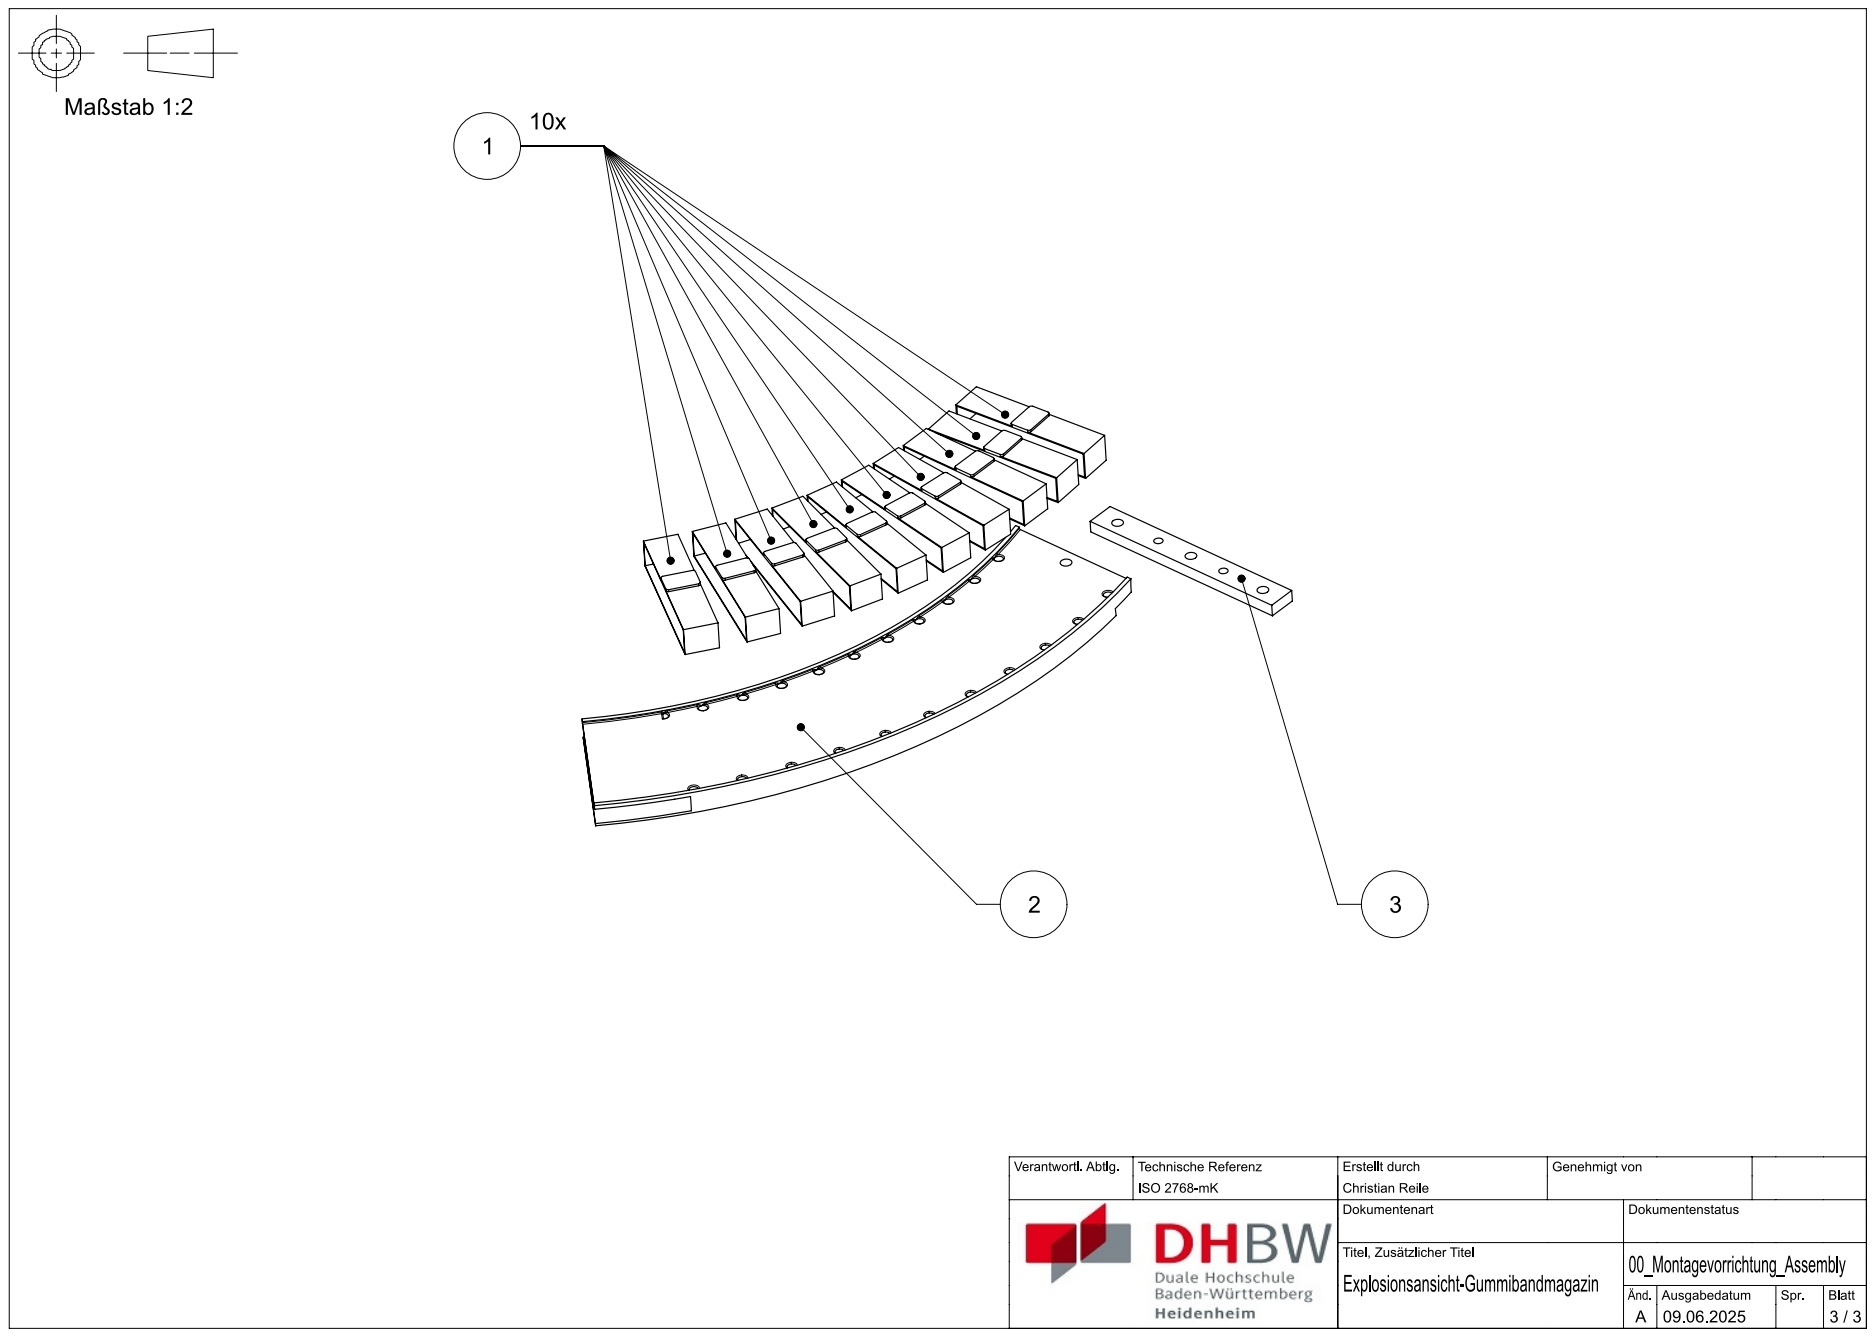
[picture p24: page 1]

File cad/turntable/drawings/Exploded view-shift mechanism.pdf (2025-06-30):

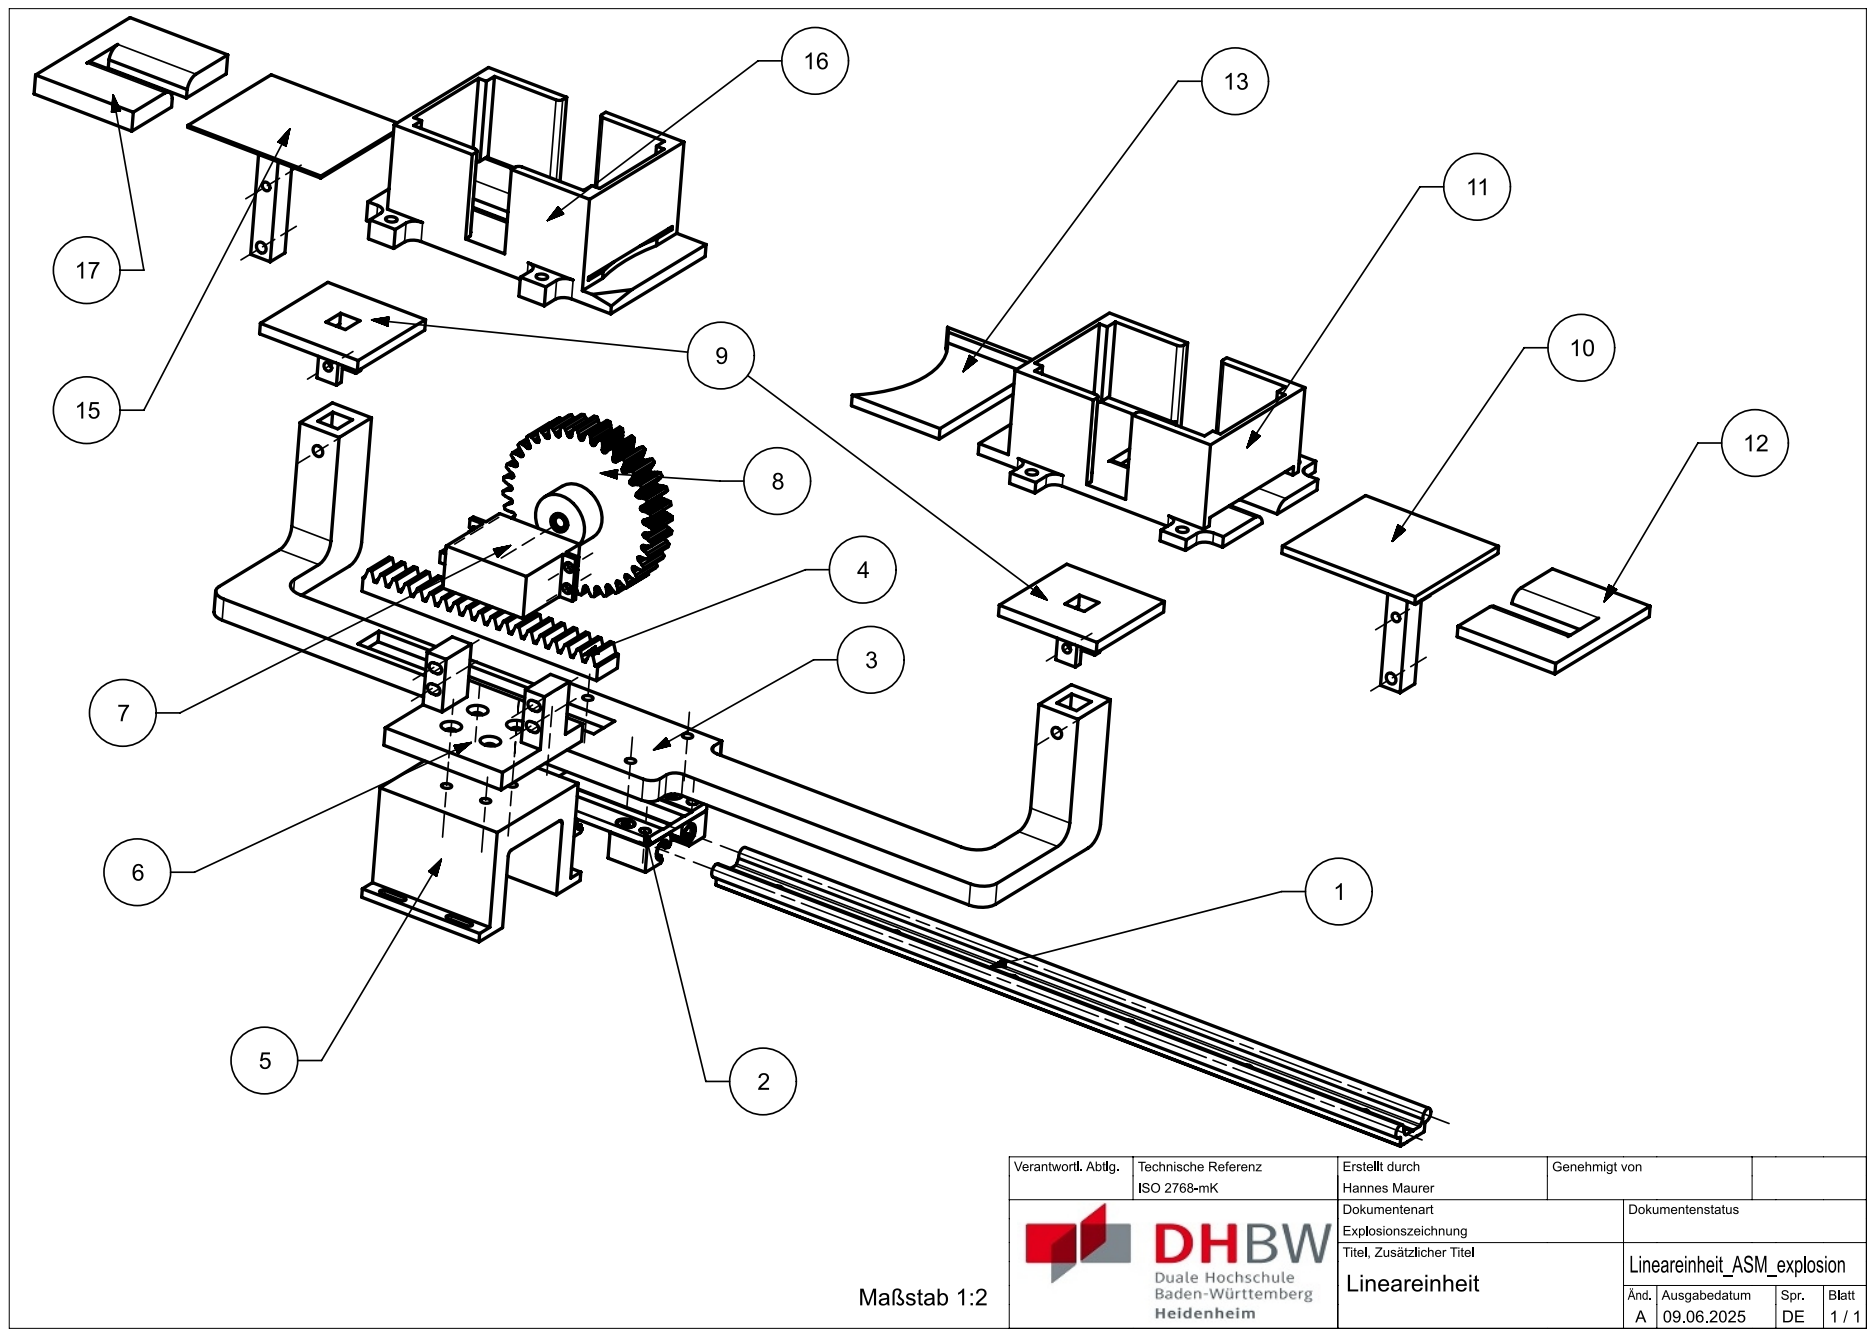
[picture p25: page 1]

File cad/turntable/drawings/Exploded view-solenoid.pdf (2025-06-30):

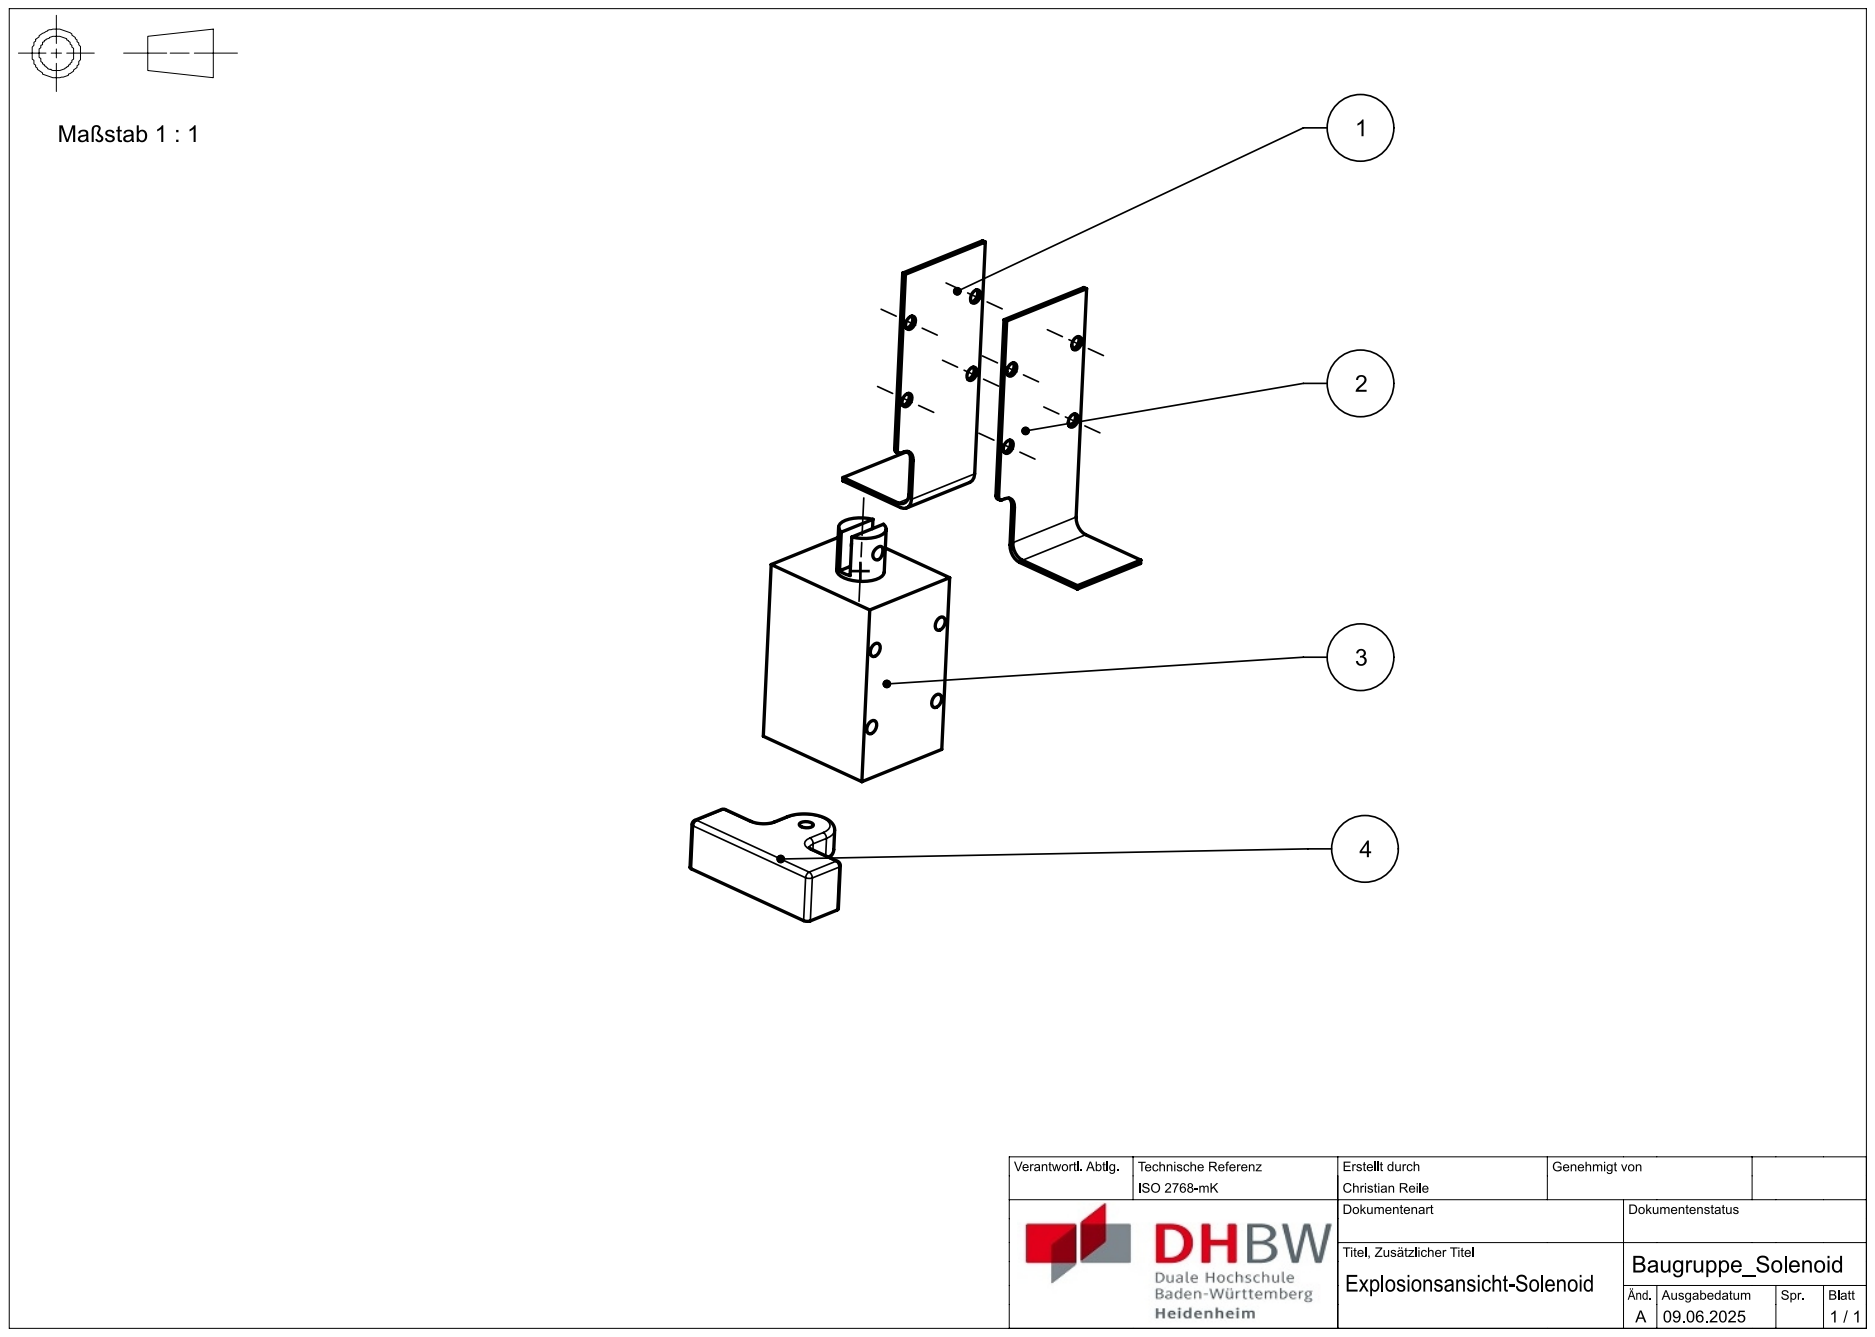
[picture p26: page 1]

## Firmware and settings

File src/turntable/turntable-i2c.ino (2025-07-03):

#include <Servo.h>
#include <math.h>
#include <Wire.h>

// ===== Status- und Befehlskonstanten =====
const byte ROBO_BUSY       = 104;
const byte ROBO_IDLE       = 116;
const byte ROBO_MOVE_A     = 10;
const byte ROBO_MOVE_TEST  = 20;
const byte CMD_CALIBRATE   = 90;
const byte CMD_STOP        = 99;
const byte CMD_CONTINUE    = 98;

// ===== Servo-Konfiguration =====
Servo servos[6];
int initAngles[6] = {90, 20, 70, 90, 112, 30};
int preAngles[6]  = {77, 20, 70, 85, 112, 30};
int asmAngles[6]  = {77, 8, 61, 85, 112, 30};
int asm2Angles[6] = {45, 8, 61, 85, 112, 30};
int asm3Angles[6] = {58, 8, 61, 85, 112, 30};

// ===== Steuerdaten =====
String input;
int stueckzahl = 0;
int s1_winkel[11] = {58, 72, 77, 82, 87, 92, 97, 102, 107, 112, 117}; // Index 1–10

// ===== I2C-Kommunikation =====
volatile byte i2c_command = 0;
volatile byte i2c_status = ROBO_IDLE;
volatile byte pending_status = 1;  // 1 = leer, sonst: Rückgabe
volatile bool stop_requested = false;

// ===== Bewegungshilfen =====
bool waitWithStop(unsigned long ms) {
  unsigned long start = millis();
  while (millis() - start < ms) {
    checkSerialControl();
    if (checkStop()) return true;
    delay(1);
  }
  return false;
}

bool checkStop() {
  if (stop_requested) {
    Serial.println("NOTAUS erkannt – Bewegung gestoppt");
    i2c_status = ROBO_IDLE;
    pending_status = CMD_STOP;
    return true;
  }
  return false;
}

void checkSerialControl() {
  if (Serial.available()) {
    String cmd = Serial.readStringUntil('\n');
    cmd.trim();
    if (cmd.equalsIgnoreCase("STOP")) {
      stop_requested = true;
      Serial.println("STOP erkannt (Serial)");
    } else if (cmd.equalsIgnoreCase("CONTINUE")) {
      stop_requested = false;
      Serial.println("CONTINUE erkannt (Serial)");
    }
  }
}

// ===== Gleichzeitige Bewegung aller Servos mit sanfter Kurve =====
void smoothMoveAll(int targets[6]) {
  const int steps = 50;
  const int delayPerStep = 15;

  int start[6];
  for (int i = 0; i < 6; i++) start[i] = initAngles[i];

  for (int i = 0; i <= steps; i++) {
    checkSerialControl();
    if (checkStop()) return;

    float t = (float)i / steps;
    float eased = t < 0.5 ? 2 * t * t : -1 + (4 - 2 * t) * t;

    for (int j = 0; j < 6; j++) {
      int pos = start[j] + (targets[j] - start[j]) * eased;
      servos[j].write(pos);
    }

    if (waitWithStop(delayPerStep)) return;
  }

  for (int i = 0; i < 6; i++) initAngles[i] = targets[i];
}

// ===== Bewegungsabläufe =====
void moveA() {
  Serial.println("Starte Move A");
  i2c_status = ROBO_BUSY;

  if (stueckzahl >= 1 && stueckzahl <= 10) {
    int s1 = s1_winkel[stueckzahl];
    preAngles[0] = s1;
    asmAngles[0] = s1;
  }

  smoothMoveAll(preAngles);
  if (waitWithStop(200)) return;
  smoothMoveAll(asmAngles);
  if (waitWithStop(200)) return;
  smoothMoveAll(asm2Angles);
  if (waitWithStop(300)) return;
  smoothMoveAll(asm3Angles);
  if (waitWithStop(200)) return;
  smoothMoveAll(preAngles);
  if (waitWithStop(1000)) return;

  i2c_status = ROBO_IDLE;
  pending_status = 115;
  Serial.println("Move A abgeschlossen");
}

void moveCAL() {
  Serial.println("Starte Kalibrierung");
  i2c_status = ROBO_BUSY;

  int target[6] = {90, 20, 70, 84, 110, 30};
  smoothMoveAll(target);
  if (waitWithStop(1000)) return;

  for (int i = 0; i < 6; i++) initAngles[i] = target[i];

  i2c_status = ROBO_IDLE;
  pending_status = CMD_CALIBRATE;
  Serial.println("Kalibrierung abgeschlossen");
}

void moveTest() {
  Serial.println("Starte moveTest");
  i2c_status = ROBO_BUSY;

  for (int st = 1; st <= 10; st++) {
    if (checkStop()) return;

    int pos_pre[6], pos_asm[6], pos_reset[6];
    for (int i = 0; i < 6; i++) {
      pos_pre[i] = preAngles[i];
      pos_asm[i] = asmAngles[i];
      pos_reset[i] = preAngles[i];
    }

    pos_pre[0] = s1_winkel[st];
    pos_asm[0] = s1_winkel[st];
    pos_reset[0] = 58;

    smoothMoveAll(pos_pre);
    if (waitWithStop(300)) return;
    smoothMoveAll(pos_asm);
    if (waitWithStop(500)) return;
    smoothMoveAll(pos_pre);
    if (waitWithStop(500)) return;
    smoothMoveAll(pos_reset);
    if (waitWithStop(500)) return;
  }

  i2c_status = ROBO_IDLE;
  pending_status = ROBO_MOVE_TEST;
  Serial.println("moveTest abgeschlossen");
}

// ===== I2C-Kommunikation =====
void receiveEvent(int howMany) {
  while (Wire.available()) {
    byte value = Wire.read();

    if (value == CMD_STOP) {
      stop_requested = true;
      Serial.println("STOP erkannt (I2C)");
    } else if (value == CMD_CONTINUE) {
      stop_requested = false;
      Serial.println("CONTINUE erkannt (I2C)");
    } else {
      i2c_command = value;
      Serial.print("I2C Befehl empfangen: ");
      Serial.println(i2c_command);
    }
  }
}

void requestEvent() {
  if (pending_status != 1) {
    Wire.write(pending_status);
    Serial.print("I2C Antwort gesendet (done): ");
    Serial.println(pending_status);
    pending_status = 1;
  } else {
    Wire.write(i2c_status);
    Serial.print("I2C Antwort gesendet (status): ");
    Serial.println(i2c_status);
  }
}

// ===== Setup & Loop =====
void setup() {
  Serial.begin(9600);
  Serial.println("Bereit. Sende CAL, A1–10, TEST, STOP oder CONTINUE");

  Wire.begin(0x08);
  Wire.onReceive(receiveEvent);
  Wire.onRequest(requestEvent);

  servos[0].attach(3);
  servos[1].attach(5);
  servos[2].attach(6);
  servos[3].attach(10);
  servos[4].attach(9);
  servos[5].attach(11);

  moveCAL(); // Initiale Kalibrierung
}

void loop() {
  checkSerialControl();

  if (Serial.available()) {
    input = Serial.readStringUntil('\n');
    input.trim();

    if (input.equalsIgnoreCase("CAL")) moveCAL();
    else if (input.equalsIgnoreCase("TEST")) moveTest();
    else if (input.startsWith("A") && input.length() >= 2) {
      int num = input.substring(1).toInt();
      if (num >= 1 && num <= 10) {
        stueckzahl = num;
        moveA();
      }
    }
  }

  if (i2c_command != 0) {
    Serial.print("Handling Command: ");
    Serial.println(i2c_command);
    if (i2c_command == CMD_CALIBRATE) moveCAL();
    else if (i2c_command >= ROBO_MOVE_A && i2c_command <= ROBO_MOVE_A + 9) {
      stueckzahl = i2c_command - ROBO_MOVE_A + 1;
      moveA();
    } else if (i2c_command == ROBO_MOVE_TEST) moveTest();
    i2c_command = 0;
  }
}

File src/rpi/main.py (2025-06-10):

#!/usr/bin/env python3
import smbus
import time
import RPi.GPIO as GPIO
import threading

# I2C-Adressen
TURNTABLE_ADDR = 0x09
ROBO_ADDR = 0x08
M5DIAL_ADDR = 0x10

# Befehle an Roboter/Drehteller
TURN_MOVE_ASM = 30
TURN_MOVE_SND = 40
ROBO_MOVE_A = 10
CMD_CONTINUE = 98
CMD_STOP = 99
CMD_CAL = 90

# Signale vom M5Dial
DIAL_START = 1
DIAL_STOP = 2
DIAL_CONTINUE = 3  # Antwort vom M5Dial (z. B. für "weiter")

# Status-Rückmeldungen
DONE_1 = 105
DONE_2 = 115
DONE_3 = 125

# GPIO
NOTAUS_PIN = 17
bus = smbus.SMBus(1)

# Steuer-Flags
pause_flag = threading.Event()
start_flag = threading.Event()
bus_lock = threading.Lock()

def init_gpio():
    GPIO.setmode(GPIO.BCM)
    GPIO.setup(NOTAUS_PIN, GPIO.IN, pull_up_down=GPIO.PUD_DOWN)

def is_notaus_active():
    return GPIO.input(NOTAUS_PIN) == GPIO.HIGH

def send_command(addr, cmd, name):
    with bus_lock:
        print(f"[{name}] → Sende Befehl {cmd} an {hex(addr)}")
        try:
            bus.write_byte(addr, cmd)
        except Exception as e:
            print(f"[{name}] Fehler beim Senden: {e}")

def wait_for_idle(addr, idle_value, name):
    print(f"[{name}] Warte auf Status {idle_value} von {hex(addr)}...")
    while True:
        if pause_flag.is_set():
            print(f"[{name}] → Pause erkannt – warte...")
            time.sleep(1)
            continue
        try:
            with bus_lock:
                status = bus.read_byte(addr)
            print(f"[{name}] Status: {status}")
            if status == idle_value:
                print(f"[{name}] abgeschlossen.")
                return
        except Exception as e:
            print(f"[{name}] Fehler beim Lesen: {e}")
        time.sleep(0.5)

def monitor_m5dial():
    while True:
        try:
            with bus_lock:
                status = bus.read_byte(M5DIAL_ADDR)

            if status == DIAL_STOP and not pause_flag.is_set():
                print("[M5Dial] NOT-AUS erkannt – pausiere System")
                pause_flag.set()
                send_command(ROBO_ADDR, CMD_STOP, "Roboter")
                send_command(TURNTABLE_ADDR, CMD_STOP, "Drehteller")
                send_command(M5DIAL_ADDR, CMD_CONTINUE, "M5Dial (zeige Quittierung)")  # 98 = zeige Popup

            elif status == DIAL_CONTINUE and pause_flag.is_set():
                print("[M5Dial] Quittierung erkannt – sende CONTINUE an Geräte")
                pause_flag.clear()
                send_command(ROBO_ADDR, CMD_CONTINUE, "Roboter")
                send_command(TURNTABLE_ADDR, CMD_CONTINUE, "Drehteller")

            elif status == DIAL_START and not start_flag.is_set():
                print("[M5Dial] START erkannt – Ablauf starten")
                start_flag.set()

        except Exception as e:
            print("[M5Dial] Fehler:", e)

        time.sleep(0.5)

def monitor_console():
    while True:
        cmd = input(">> ").strip().lower()
        if cmd == "stop":
            print("[Console] STOP erkannt")
            pause_flag.set()
            send_command(ROBO_ADDR, CMD_STOP, "Roboter")
            send_command(TURNTABLE_ADDR, CMD_STOP, "Drehteller")
        elif cmd == "cont":
            print("[Console] CONTINUE erkannt")
            pause_flag.clear()
            send_command(ROBO_ADDR, CMD_CONTINUE, "Roboter")
            send_command(TURNTABLE_ADDR, CMD_CONTINUE, "Drehteller")
        elif cmd == "cal":
            print("[Console] KALIBRIERUNG")
            send_command(ROBO_ADDR, CMD_CAL, "Roboter")
            send_command(TURNTABLE_ADDR, CMD_CAL, "Drehteller")
        else:
            print("[Console] Unbekannter Befehl:", cmd)

def main():
    print("[Init] Sende CONTINUE und führe Kalibrierung durch")
    send_command(ROBO_ADDR, CMD_CONTINUE, "Roboter")
    send_command(TURNTABLE_ADDR, CMD_CONTINUE, "Drehteller")
    time.sleep(1)
    send_command(ROBO_ADDR, CMD_CAL, "Roboter")
    send_command(TURNTABLE_ADDR, CMD_CAL, "Drehteller")
    time.sleep(3)
    send_command(ROBO_ADDR, 20, "Roboter")

    # Hintergrundthreads starten
    threading.Thread(target=monitor_m5dial, daemon=True).start()
    threading.Thread(target=monitor_console, daemon=True).start()

    print("[System] Warte auf Startsignal vom M5Dial...")

    while True:
        try:
            if start_flag.is_set() and not pause_flag.is_set():
                print("[System] Ablauf beginnt...")
                start_flag.clear()

                for stueck in range(1, 11):
                    if pause_flag.is_set(): break

                    print(f"[System] Bearbeite Stück {stueck}")

                    send_command(TURNTABLE_ADDR, TURN_MOVE_ASM, "Drehteller ASM")
                    wait_for_idle(TURNTABLE_ADDR, DONE_1, "Drehteller ASM")

                    send_command(ROBO_ADDR, ROBO_MOVE_A + (stueck - 1), "Roboter MOVE_A")
                    wait_for_idle(ROBO_ADDR, DONE_2, "Roboter MOVE_A")

                    send_command(TURNTABLE_ADDR, TURN_MOVE_SND, "Drehteller SND")
                    wait_for_idle(TURNTABLE_ADDR, DONE_3, "Drehteller SND")

                print("[System] Ablauf abgeschlossen.")

        except KeyboardInterrupt:
            print("[System] Beendet durch Nutzer.")
            break
        except Exception as e:
            print("[System] Fehler:", e)

        time.sleep(0.5)

    GPIO.cleanup()

if __name__ == "__main__":
    main()

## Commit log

2025-05-27 first i2c worked,on pcb not
2025-05-27 added i2c.py
2025-05-28 i2c robo functions
2025-05-28 added 2 proccesses for security and i2c communication
2025-05-28 worker for each assembly added
2025-05-28 i2c fix
2025-06-09 added i2c-test.py
2025-06-09 added i2c turn test
2025-06-09 i2c responses check
2025-06-09 2nd better working, fixed dial missinterpretation
    [main.py]
2025-06-30 added Dokumentation
    [base.stp, basegelenk.stp, greiferarm_rechts.stp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]
2025-07-03 added Readme
    [1_Anforderungsliste.xlsx, 2_Vorlage_Paarweiser_Vergleich.xlsx, 3_Vorlage_T-Tabelle.xlsx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]
